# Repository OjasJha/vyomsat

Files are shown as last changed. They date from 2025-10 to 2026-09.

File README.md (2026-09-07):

> [!IMPORTANT]
> ## 🚀 VyomSat has moved
>
> Active development now lives under the **[VyomSat](https://github.com/vyomsat)** GitHub organization. This personal repository is no longer the source of truth for the classroom satellite, ground software, or educational research.

| 🧩 **This repository** | 🛰️ **VyomSat Alpha** |
|:---|:---|
| Archived **FlatSat** | Current **1U** classroom CubeSat |
| 🔌 Breadboard wiring, buses, and subsystem bring-up | 🧱 Custom **PCB**, enclosure, and functioning assembly |
| 🧪 Bench testing and historical reference | 🛠️ Hardware, firmware, and mission-cycle testing |
| 📦 Not the source of truth | ⚠️ Educational bench platform (**not flight-qualified**) |

### 🔗 Continue under the VyomSat organization

| | Project | What you will find |
|:---:|:---|:---|
| 🛰️ | **[VyomSat Alpha](https://github.com/vyomsat/vyomsat-alpha)** | PCB-based **1U** classroom CubeSat: hardware, firmware, enclosure, subsystem validation, and mission-cycle testing |
| 📡 | **[Ground Station](https://github.com/vyomsat/vyomsat-alpha-ground-station)** | Browser mission console: USB telemetry, spacecraft commands, parsed health data, and live GPS visualization |
| 🎓 | **[Impact Study](https://github.com/vyomsat/vyomsat-alpha-impact-study)** | Educational-efficacy research: study design, field data, and analysis |

> [!WARNING]
> ⚠️ **Not flight-qualified.** VyomSat Alpha is a functioning educational CubeSat for the classroom bench. It is not spacecraft hardware intended for orbital deployment.

> [!NOTE]
> 📦 This repository is **archived** and retained for historical reference. Please star, fork, open issues, and contribute on the organization repositories above.

---

# VyomSat - Essence of Space. Built by You.

**A step-by-step learning kit for exploring microsatellite technology through hands-on CubeSat development**

🛰️ **Learn by Building** | 📚 **Model-Based Learning** | 🔧 **Off-the-Shelf Components** | 🚀 **Space Technology Made Accessible**

---

## 📖 Overview

VyomSat is an educational kit designed to make space technology accessible through hands-on learning. This repository guides you through building a functional CubeSat prototype from the ground up, one subsystem at a time, using readily available components and a Raspberry Pi Pico microcontroller.

### The Name

**Vyom** (व्योम) means sky, heavens, or outer space in Sanskrit.  
**Sat** ties to "satellite," but in Sanskrit also means truth, being, existence.

VyomSat can be read as:
- **"Space Satellite"** - straightforward and modern
- **"Truth of Space" / "Essence of the Sky"** - deeper, Sanskrit-inspired meaning

Short, internationally pronounceable, with both technical and cultural essence. 🚀✨

---

## 🎯 Mission & Vision

### Why This Project Exists

This project was born from a gap in STEM education: high school students often lack opportunities for truly challenging, real-world engineering experiences beyond rudimentary activities like water rockets or spaghetti towers. VyomSat aims to fill this gap by providing a comprehensive, hands-on introduction to space systems engineering.

### Mission
**Make space technology accessible to learners of all ages and expertise levels.**

### Vision
**Share knowledge about microsatellite technology through a practical kit that offers hands-on training and meaningful interaction with real engineering systems.**

Space is the final frontier, and it's also one of the best ways to learn engineering in a multidisciplinary way.

---

## 👥 Who Is This For?

**Target Audience:**
- 🔬 STEM enthusiasts
- 🛠️ Tinkerers and makers
- 🎨 DIY electronics hobbyists
- 🌌 Anyone interested in space, CubeSats, and satellites
- 📚 **Age no bar!** Anyone with high school-level science and basic programming can jump in

**Prerequisites:**
- Basic breadboarding skills
- Familiarity with Raspberry Pi Pico
- Basic MicroPython programming (or willingness to learn)
- A lot of curiosity! 🧠✨

---

## 🚀 Why CubeSats? Why Model-Based Learning?

### CubeSats as Learning Platforms

CubeSats (miniature satellites using standardized 10×10×10 cm units) are excellent platforms for learning because they:
- Cover **multidisciplinary engineering**: electrical, mechanical, software, communications
- Demonstrate **real-world constraints**: power, mass, volume, thermal management
- Introduce **systems engineering**: subsystems must work together seamlessly
- Are **achievable**: built with off-the-shelf components at educational scales
- Reflect **modern space technology**: actual CubeSats fly in orbit regularly

### Model-Based, Step-by-Step Learning

This repository uses a **progressive building approach**:
1. Start with foundational subsystems (power, communication)
2. Add sensors and payloads incrementally
3. Integrate everything into a working prototype
4. Understand the **what, why, and how** of each component

Each step builds on the previous one, allowing you to:
- ✅ Master one concept before moving to the next
- ✅ Troubleshoot issues in isolated subsystems
- ✅ Understand system integration challenges
- ✅ Build confidence through working prototypes

---

## 📂 Repository Structure

This repository contains **6 progressive steps**, each adding new capabilities to your CubeSat:

### **Step 0: EPS + COM Integration** (`step-00-eps-com/`)
**Electrical Power System (EPS) and Communication (COM)**
- Battery voltage monitoring via ADC
- OLED display for local visualization
- XBee UART communication for wireless telemetry
- Foundation for all subsequent steps

**Key Components:** Raspberry Pi Pico, OLED display (SSD1306), XBee module  
**Learn:** Power monitoring, I2C, UART, telemetry basics

---

### **Step 1: 9-Axis IMU Integration** (`step-01-9axis/`)
**Attitude Determination and Control System (ADCS) - Sensing**
- MPU9250 9-axis IMU (accelerometer + gyroscope + magnetometer)
- Pitch, roll, and heading calculations
- Sensor fusion for accurate attitude estimation
- Command-triggered comprehensive attitude data capture

**New Components:** MPU9250 9-axis IMU  
**Learn:** Inertial measurement, sensor fusion, attitude determination

---

### **Step 2: GPS Integration** (`step-02-gps/`)
**Navigation and Positioning**
- NEO-6M GPS module for precise location tracking
- Latitude, longitude, altitude, and satellite data
- GPS time synchronization with timezone support
- Speed and course over ground measurement

**New Components:** NEO-6M GPS module  
**Learn:** NMEA sentence parsing, GPS fundamentals, position tracking

---

### **Step 3: Camera Integration** (`step-03-camera/`)
**Payload - Earth Observation**
- ArduCam Mega 3MP camera for high-resolution imaging
- JPEG image capture with configurable quality
- Auto-incremented filenames for organized storage
- Command-triggered photo capture

**New Components:** ArduCam Mega 3MP (OV5642)  
**Learn:** SPI camera interfacing, image capture, payload operations

---

### **Step 4: SD Card Integration** (`step-04-sd/`)
**Data Storage and Mission Data Logging**
- Micro SD card module for comprehensive data logging
- Multi-sensor data capture (housekeeping, 9-axis, GPS)
- Multi-cycle data collection with timestamped log files
- FAT32 filesystem support for easy data retrieval

**New Components:** Micro SD Card module, Micro SD card (up to 32GB)  
**Learn:** Filesystem operations, data logging, long-term storage

---

### **Step 5: Photo-to-SD Automatic Transfer** (`step-05-photo-move.py/`)
**Intelligent File Management**
- Automatic image transfer to SD card after capture
- Flash memory freed immediately after each photo
- Preserved auto-incremented filenames
- Centralized storage for all mission data

**New Features:** Enhanced camera workflow, automated file management  
**Learn:** Storage optimization, mission operations, file I/O

---

## 🛠️ What's Provided for Each Step

Every step directory includes:

- ✅ **Complete README.md** - Detailed documentation with theory and operation
- ✅ **Circuit Schematic** - Full electrical connections (`*_schematic.png`)
- ✅ **Breadboard Layout** - Physical wiring guide (`*_breadboard.png`)
- ✅ **Bill of Materials** - Complete parts list with specifications (`*_bom.html`)
- ✅ **Fritzing File** - Editable circuit diagram (`*.fzz`)
- ✅ **MicroPython Code** - Modular manager scripts for each subsystem

### Fritzing Software

Circuit diagrams were created using [**Fritzing**](https://fritzing.org/), an open-source electronics design tool.

📥 **Download Fritzing:** [fritzing.org/download](https://fritzing.org/download/)

You can view, edit, or customize the `.fzz` files to adapt the designs to your needs.

---

## 📚 Required Libraries

All sensor and breakout board libraries are maintained in a separate repository for modularity and reusability.

🔗 **MicroPython Libraries:** [github.com/OjasJha/micropython-lib](https://github.com/OjasJha/micropython-lib.git)

**To get started:**
```bash
git clone https://github.com/OjasJha/micropython-lib.git
```

**Copy required libraries** (listed in each step's README) to your Raspberry Pi Pico in a flat structure alongside the VyomSat manager modules.

---

## 🚦 Quick Start Guide

### 1. **Hardware Setup**
- Gather components from the Bill of Materials (BOM) for your chosen step
- Follow the breadboard layout diagram for wiring
- Double-check connections against the schematic

### 2. **Software Setup**
- Install [Thonny IDE](https://thonny.org/) for MicroPython development
- Install MicroPython firmware on your Raspberry Pi Pico 2 or Pico W
- Download required libraries from the [micropython-lib repository](https://github.com/OjasJha/micropython-lib.git)

### 3. **Upload Code**
- Copy library files (e.g., `uart_handler.py`, `ssd1306_handler.py`) to Pico
- Copy VyomSat manager modules (e.g., `vyomsat_battery_manager.py`) to Pico
- Copy main script (`vyomsat.py`) to Pico

### 4. **Run and Test**
- Open Thonny, connect to your Pico
- Run `vyomsat.py` or rename it to `main.py` for auto-start on boot
- Monitor USB serial console (115200 baud) for debug output
- Test commands via XBee UART interface

### 5. **Build Progressively**
- Start with Step 0 to establish the foundation
- Add one subsystem at a time (Steps 1 → 2 → 3 → 4 → 5)
- Test thoroughly at each step before proceeding
- Refer to individual README files for detailed instructions

---

## 📊 Communication Interfaces Summary

By Step 5, your CubeSat prototype will use:

| Interface | Pins | Speed | Purpose |
|---|---|---|---|
| **SPI0** | GP16/17/18/19 | 8 MHz | ArduCam Mega 3MP Camera |
| **SPI1** | GP10/11/12/13 | 1 MHz | Micro SD Card Module |
| **UART0** | GP0/GP1 | 9600 bps | XBee Communication |
| **UART1** | GP4/GP5 | 9600 bps | NEO-6M GPS Module |
| **I2C0** | GP6/GP7 | 400 kHz | SSD1306 OLED Display |
| **I2C1** | GP20/GP21 | 400 kHz | MPU9250 9-Axis IMU |
| **ADC** | GP28 | - | Battery Voltage Monitoring |

---

## 🎓 Learning Outcomes

By completing this project, you will:

### Technical Skills
- ✅ Understand **CubeSat subsystems**: EPS, COM, ADCS, GPS, Camera, Data Storage
- ✅ Master **communication protocols**: I2C, SPI, UART, ADC
- ✅ Learn **sensor integration**: IMU, GPS, camera interfacing
- ✅ Practice **embedded programming**: MicroPython on Raspberry Pi Pico
- ✅ Develop **systems thinking**: integrating multiple subsystems
- ✅ Handle **real-world constraints**: power, memory, timing, bus contention

### Engineering Practices
- ✅ **Modular design**: Each subsystem isolated and testable
- ✅ **Progressive integration**: Build complexity incrementally
- ✅ **Error handling**: Graceful degradation when components fail
- ✅ **Documentation**: Reading schematics, datasheets, and technical docs
- ✅ **Troubleshooting**: Debugging hardware and software issues

### Space Technology Knowledge
- ✅ How **satellites monitor power** (battery voltage sensing)
- ✅ How **satellites determine attitude** (IMU sensors and fusion algorithms)
- ✅ How **satellites know their position** (GPS and NMEA parsing)
- ✅ How **satellites capture images** (camera payloads)
- ✅ How **satellites store data** (onboard storage and file management)
- ✅ How **satellites communicate** (telemetry and command interfaces)

### What You'll Have Built
A **working CubeSat prototype** that:
- 🔋 Monitors battery voltage
- 📡 Communicates wirelessly via XBee
- 📺 Displays telemetry on OLED screen
- 🧭 Tracks orientation and motion
- 🛰️ Determines GPS position
- 📷 Captures high-resolution images
- 💾 Logs all sensor data to SD card
- ⚡ Manages storage efficiently

---

## 🧑‍💻 Supported UART Commands

Once fully built (Step 5), your CubeSat responds to these commands via XBee:

| Command | Function | Introduced In |
|---|---|---|
| **`v`** | Battery voltage reading | Step 0 |
| **`a`** | 9-axis IMU attitude data | Step 1 |
| **`g`** | GPS position and diagnostics | Step 2 |
| **`c`** | Camera capture + SD transfer | Step 3 (enhanced in Step 5) |
| **`s`** | Multi-sensor data logging to SD | Step 4 |

---

## 🔧 Built With Off-the-Shelf Components

All components are readily available from electronics suppliers like Adafruit, SparkFun, Amazon, or local vendors:

- **Raspberry Pi Pico 2** or **Pico W** (microcontroller)
- **SSD1306 OLED Display** (128×64, I2C)
- **MPU9250 9-Axis IMU** (GY-9250 module)
- **NEO-6M GPS Module** (GY-GPS6MV2)
- **ArduCam Mega 3MP Camera** (OV5642, SPI)
- **Micro SD Card Module** (SPI)
- **XBee Module** (or compatible UART device)
- Breadboard, jumper wires, resistors, batteries

**Total cost:** Approximately $80-$150 USD depending on component sources.

---

## 📁 Project Structure

```
vyomsat/
│
├── README.md                          # This file - repository overview
├── LICENSE                            # MIT License
│
├── step-00-eps-com/                   # Step 0: Power & Communication
│   ├── README.md                      # Detailed step documentation
│   ├── vyomsat.py                     # Main integration script
│   ├── vyomsat_battery_manager.py     # Battery voltage monitoring
│   ├── vyomsat_oled_manager.py        # OLED display handler
│   ├── vyomsat_xbee_manager.py        # XBee reset handler
│   ├── eps-com_schematic.png          # Circuit schematic
│   ├── eps-com_breadboard.png         # Breadboard layout
│   ├── eps-com_bom.html               # Bill of materials
│   └── eps-com.fzz                    # Fritzing design file
│
├── step-01-9axis/                     # Step 1: 9-Axis IMU
│   ├── README.md
│   ├── vyomsat.py
│   ├── vyomsat_9axis_manager.py       # NEW: IMU handler
│   ├── [other managers]
│   ├── 9axis_schematic.png
│   ├── 9axis_breadboard.png
│   ├── 9axis_bom.html
│   └── 9axis.fzz
│
├── step-02-gps/                       # Step 2: GPS Integration
│   ├── README.md
│   ├── vyomsat.py
│   ├── vyomsat_gps_manager.py         # NEW: GPS handler
│   ├── [other managers]
│   ├── gps_schematic.png
│   ├── gps_breadboard.png
│   ├── gps_bom.html
│   └── gps.fzz
│
├── step-03-camera/                    # Step 3: Camera Integration
│   ├── README.md
│   ├── vyomsat.py
│   ├── vyomsat_camera_manager.py      # NEW: Camera handler
│   ├── [other managers]
│   ├── camera_schematic.png
│   ├── camera_breadboard.png
│   ├── camera_bom.html
│   └── camera.fzz
│
├── step-04-sd/                        # Step 4: SD Card Logging
│   ├── README.md
│   ├── vyomsat.py
│   ├── vyomsat_sd_manager.py          # NEW: SD card handler
│   ├── [other managers]
│   ├── sd_schematic.png
│   ├── sd_breadboard.png
│   ├── sd_bom.html
│   └── sd.fzz
│
└── step-05-photo-move.py/             # Step 5: Auto Photo-to-SD
    ├── README.md
    ├── vyomsat.py                     # Enhanced with auto-transfer
    ├── vyomsat_sd_manager.py          # Enhanced with move function
    ├── [other managers]
    ├── photo-move_schematic.png
    ├── photo-move_breadboard.png
    ├── photo-move_bom.html
    └── photo-move.fzz
```

---

## 🤝 Contributing

This is an educational project developed to share knowledge about space technology. Contributions, suggestions, and improvements are welcome!

**Ways to contribute:**
- Report issues or bugs
- Suggest new features or subsystems
- Improve documentation
- Share your build photos and experiences
- Adapt designs for different hardware platforms

---

## 📜 License

**MIT License** - Copyright (c) 2025 Ojas Jha

See [LICENSE](LICENSE) file for full license text.

This project is open-source and free to use for educational purposes. You may use, modify, and distribute this project with attribution.

---

## 👨‍🚀 Author

**Ojas Jha**  
VyomSat CubeSat Education Kit  
Date: October 25, 2025

Passionate about making space technology accessible to learners worldwide. 🌍🚀

---

## 🙏 Acknowledgments

- The maker and open-source hardware communities for inspiration
- [Fritzing](https://fritzing.org/) for circuit design software
- [MicroPython](https://micropython.org/) for embedded Python support
- The CubeSat community for demonstrating that space is accessible
- High school STEM educators pushing for deeper learning experiences

---

## 🌟 Get Started Today!

Ready to build your own CubeSat prototype?

1. ⭐ **Star this repository** to bookmark it
2. 📥 **Clone or download** the repository
3. 🛒 **Order components** from the Step 0 BOM
4. 📖 **Read** `step-00-eps-com/README.md`
5. 🔧 **Start building!**

**Questions?** Open an issue or discussion. **Built something cool?** Share your results!

---

**VyomSat - Because space is for everyone. 🌌✨**

*"The essence of space, built by you."*

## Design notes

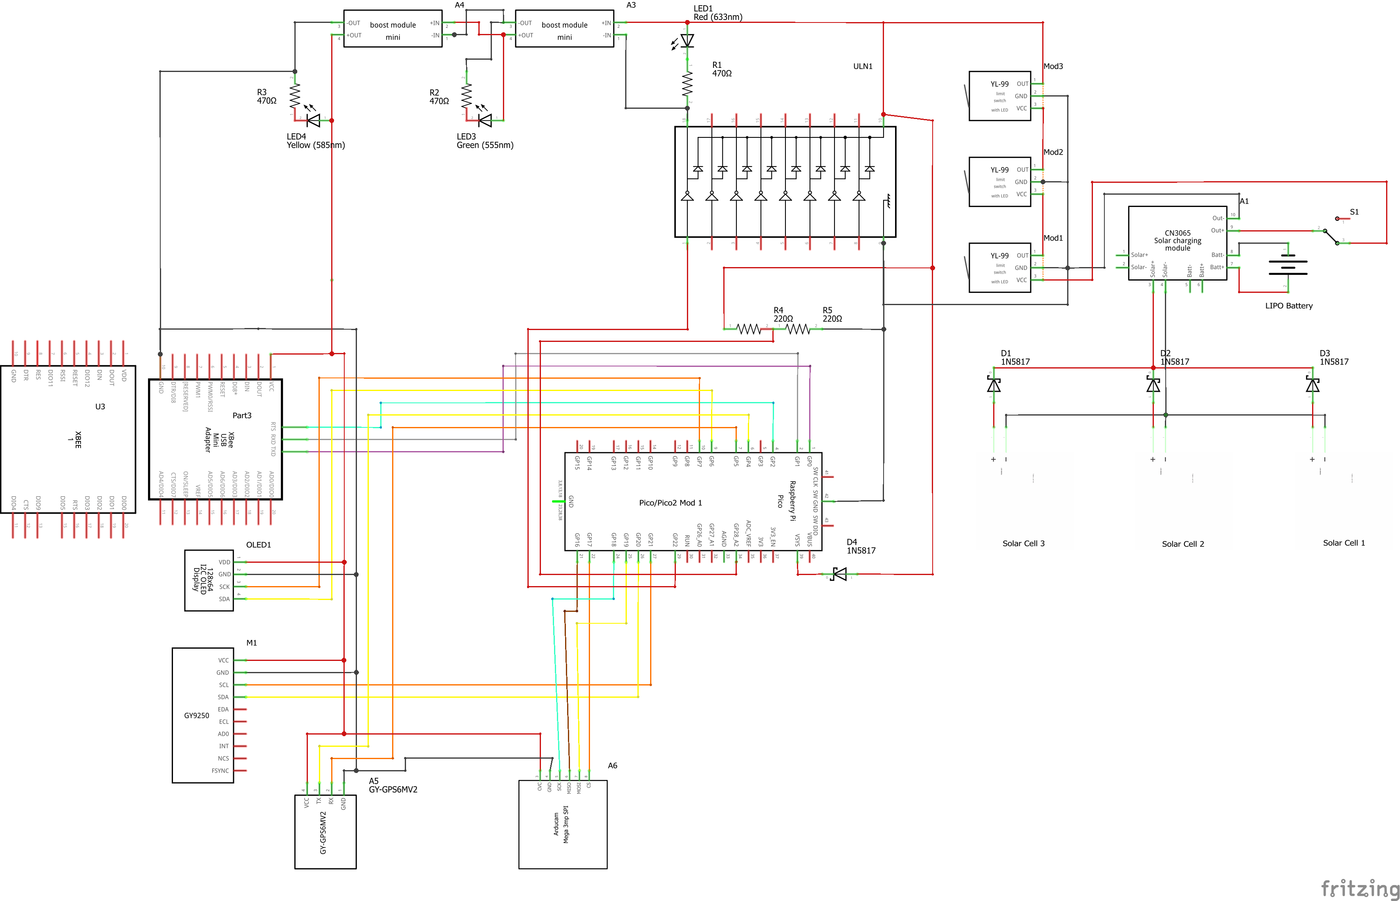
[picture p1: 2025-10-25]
step-03-camera/camera_schematic.png

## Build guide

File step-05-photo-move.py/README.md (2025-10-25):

# VyomSat Step 5: Photo Capture with Automatic SD Card Storage

**VyomSat - Essence of Space. Built by You.**

This step builds upon Step 4 (EPS + COM + 9-Axis IMU + GPS + Camera + SD Card) by adding **automatic image transfer to SD card**. When a photo is captured, the system now automatically moves it from the Pico's internal flash memory to the SD card, preserving precious onboard storage space for mission-critical operations.

## Overview

Step 5 enhances the camera imaging system with intelligent file management. The system continuously measures battery voltage, communicates via UART, provides comprehensive attitude data through the MPU9250 IMU, tracks precise geographic location using GPS satellites, captures high-quality images on command, logs sensor data to SD card, and **now automatically transfers captured images to SD card storage**.

**New in Step 5:**
- 📸 **Automatic Photo-to-SD Transfer** - Images automatically moved to SD card after capture
- 🗑️ **Flash Memory Management** - Original files deleted after successful SD transfer
- 🔄 **Seamless Integration** - Single command 'c' handles capture AND storage
- 💾 **Preserved Filenames** - Original auto-incremented names maintained on SD card
- 📺 **Enhanced Feedback** - OLED shows both capture and transfer status
- ⚡ **Optimized Storage** - Pico flash freed immediately after each photo

**Retained from Step 4:**
- 💾 Micro SD Card Module with multi-sensor data logging
- 📝 Multi-cycle sensor data capture (housekeeping, 9-axis IMU, GPS)
- 🎯 Command 's' for comprehensive sensor data logging
- 📊 Timestamped log files

**Retained from Step 3:**
- 📷 ArduCam Mega 3MP Camera with JPEG capture
- 🖼️ Auto-incremented image filenames
- 🎯 Command 'c' for camera capture (now with SD storage)

**Retained from Step 2:**
- 🛰️ NEO-6M GPS Module with position tracking
- 📍 Location Data (latitude, longitude, altitude)
- 🕐 GPS Time & Date with timezone conversion
- 🎯 Command 'g' for GPS data capture

**Retained from Step 1:**
- 🧭 MPU9250 9-Axis IMU (accelerometer, gyroscope, magnetometer)
- 📊 Attitude Data (pitch, roll, heading)
- 🎯 Command 'a' for 9-axis data capture

**Retained from Step 0:**
- 📊 Battery Voltage Monitoring
- 📺 OLED Display (128x64 SSD1306)
- 📡 UART Communication (XBee)
- 🎛️ Command Interface
- ⚡ Hardware Reset Management

## Features

### Photo-to-SD Automatic Transfer (NEW)

The enhanced camera capture system now includes intelligent file management:

- **Automatic Transfer**: Images automatically moved to SD card after capture
- **Original Filename Preserved**: Auto-incremented names maintained (e.g., `vyomsat_image_003.jpg`)
- **Flash Memory Freed**: Original file deleted from Pico after successful transfer
- **Error Handling**: Graceful degradation if SD card unavailable
- **User Feedback**: OLED displays both capture and transfer status
- **UART Responses**: ACK/NAK for both operations

**Photo Capture & Transfer Process:**
1. Command 'c' received via UART
2. OLED shows "Camera" / "Capturing..."
3. Camera captures JPEG image to Pico flash
4. Image saved with auto-incremented filename
5. OLED shows success with filename (3 seconds)
6. OLED shows "Moving to" / "SD card..."
7. File copied to SD card at `/sd/[filename]`
8. Original file deleted from Pico flash
9. OLED shows "Moved to SD!" with filename (2 seconds)
10. UART sends final ACK: "Image saved to SD card"
11. System returns to normal telemetry display

**Benefits:**
- **Storage Efficiency**: Pico flash memory freed immediately
- **Centralized Storage**: All mission data (images + logs) on SD card
- **Mission Longevity**: More photos possible without flash exhaustion
- **Easy Retrieval**: Single SD card contains all mission data
- **Automated Workflow**: No manual file management required

### SD Card Data Logging Capabilities (from Step 4)

The Micro SD Card module provides comprehensive data storage:

- **Multi-Sensor Data Logging**: Comprehensive telemetry capture
  - Housekeeping Data: Battery voltage, timestamps, system uptime
  - 9-Axis IMU Data: Accelerometer, gyroscope, magnetometer, attitude, heading
  - GPS Data: Position, altitude, time, satellites, motion, fix quality
  - Multi-cycle collection: 5 cycles by default (configurable)
  - Cycle timing: 500ms delay between cycles (configurable)

- **Image Storage**: High-resolution JPEG images
  - Auto-incremented filenames: vyomsat_image_XXX.jpg
  - Preserved from original capture
  - Stored at SD card root: /sd/
  - 3MP resolution (2048x1536 pixels)

- **File Management**: Automatic operations
  - Sensor logs: sensor_log_[timestamp].txt
  - Camera images: vyomsat_image_XXX.jpg
  - Unix timestamp for logs
  - Auto-increment counter for images
  - No file overwrites

- **SPI Communication**: High-speed SD card access
  - SPI Bus 1: 1 MHz communication speed (safe initialization)
  - 4-wire interface: SCK, MISO, MOSI, CS
  - Dedicated chip select for SD card control
  - FAT filesystem mounting

- **Card Compatibility**: Wide range of SD cards
  - SDSC (Standard Capacity): Up to 2GB, FAT16
  - SDHC (High Capacity): 2GB to 32GB, FAT32
  - Recommended: FAT32 formatted cards

## Hardware Requirements

### Components

- Raspberry Pi Pico 2 or Pico W
- SSD1306 OLED Display (128x64 pixels, I2C)
- MPU9250 9-Axis IMU Sensor Module (I2C)
- NEO-6M GPS Module (UART)
- ArduCam Mega 3MP SPI Camera Module (OV5642)
- Micro SD Card Module (SPI)
- **Micro SD Card (FAT32, up to 32GB, sufficient space for images)** ← **IMPORTANT**
- XBee module (or compatible UART device)
- Battery voltage divider circuit
- 4.7kΩ pull-up resistors for I2C lines (2x for IMU)

### Wiring Connections

| Component | Pico Pin | Description |
|---|---|---|
| **OLED Display** | | |
| SCL | GP7 | I2C Serial Clock |
| SDA | GP6 | I2C Serial Data |
| VCC | 3.3V | Power |
| GND | GND | Ground |
| **MPU9250 9-Axis IMU** | | |
| SCL | GP21 | I2C Serial Clock |
| SDA | GP20 | I2C Serial Data |
| VCC | 3.3V | Power |
| GND | GND | Ground |
| **NEO-6M GPS Module** | | |
| TX (GPS → Pico) | GP5 | UART1 Receive |
| RX (Pico → GPS) | GP4 | UART1 Transmit |
| VCC | 3.3V | Power |
| GND | GND | Ground |
| **ArduCam Mega 3MP** | | |
| SCK | GP18 | SPI0 Serial Clock |
| MISO | GP16 | SPI0 Master In Slave Out |
| MOSI | GP19 | SPI0 Master Out Slave In |
| CS | GP17 | SPI0 Chip Select |
| VCC | 3.3V or 5V | Power (check module specs) |
| GND | GND | Ground |
| **Micro SD Card Module** | | |
| SCK | GP10 | SPI1 Serial Clock |
| MISO | GP12 | SPI1 Master In Slave Out |
| MOSI | GP11 | SPI1 Master Out Slave In |
| CS | GP13 | SPI1 Chip Select |
| VCC | 3.3V or 5V | Power (module has regulator) |
| GND | GND | Ground |
| **XBee Module** | | |
| TX (Pico → XBee) | GP0 | UART0 Transmit |
| RX (XBee → Pico) | GP1 | UART0 Receive |
| RST | GP2 | Hardware Reset (optional) |
| GND | GND | Common Ground |
| **Battery Sensing** | | |
| ADC Input | GP28 | Battery voltage via divider |

> **Important Notes**: 
> - The SD Card Module uses SPI1 communication at 1 MHz (safe initialization speed)
> - **SD card should be formatted as FAT32 with sufficient free space for images**
> - Each 3MP JPEG image is typically 200KB-800KB depending on scene complexity
> - SPI Bus 0 (GP16/GP17/GP18/GP19) is dedicated to camera
> - SPI Bus 1 (GP10/GP11/GP12/GP13) is dedicated to SD card
> - UART1 (GP4/GP5) remains for GPS communication
> - UART0 (GP0/GP1) remains for XBee communication
> - The MPU9250 requires 4.7kΩ pull-up resistors on both SCL and SDA lines
> - Battery voltage must be reduced to 0-3.3V range using a voltage divider circuit
> - SD card module typically includes level shifters for 5V compatibility

### Circuit Diagrams

Visual references for hardware setup are provided using Fritzing diagrams:

#### Schematic Diagram
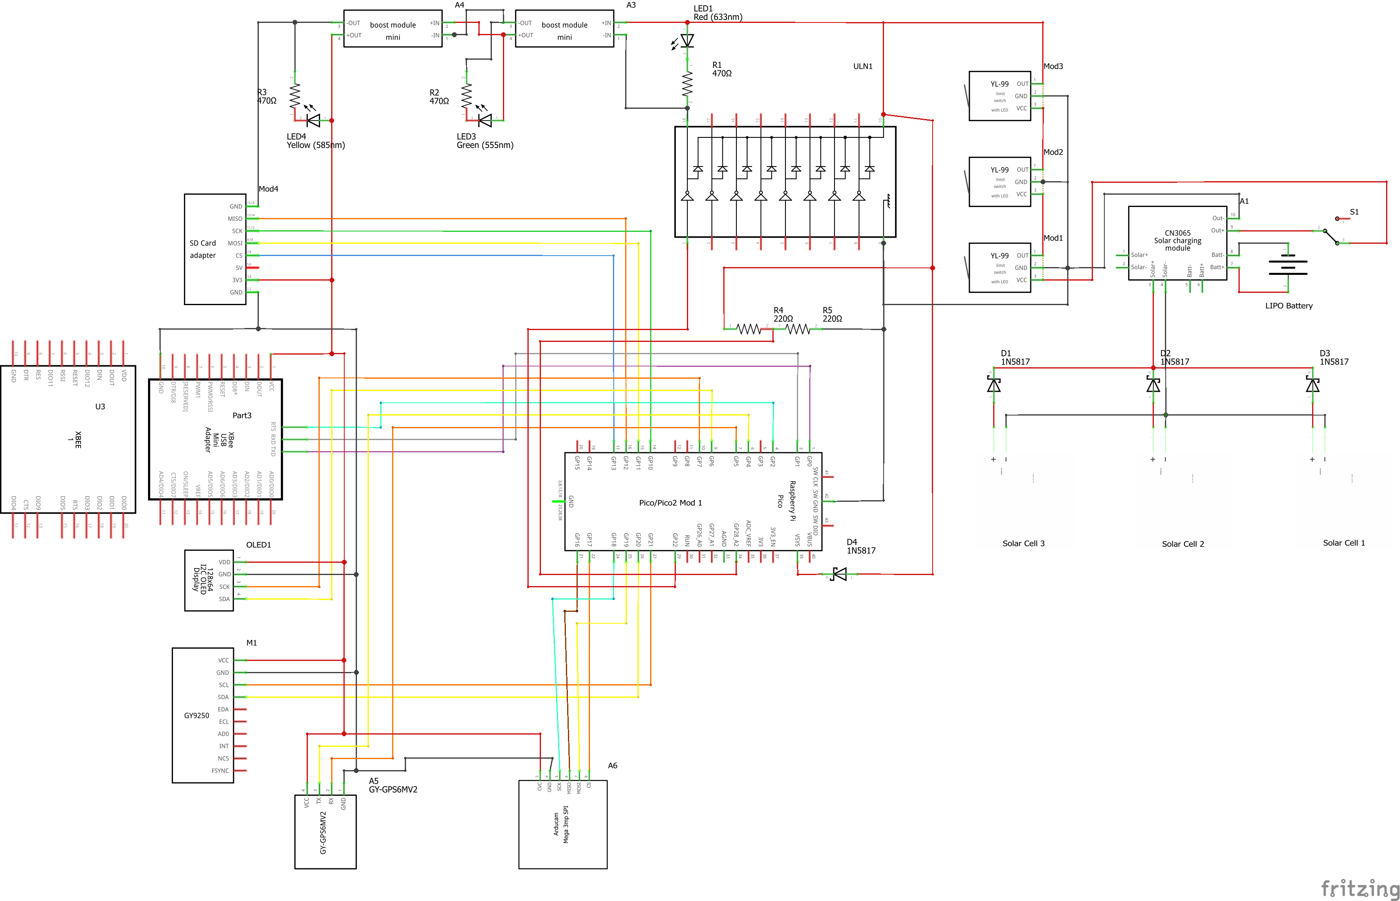
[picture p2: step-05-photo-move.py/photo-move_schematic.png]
VyomSat Photo-to-SD Schematic


The schematic shows the complete electrical connections including:
- Solar panel array with charge controller (CN3065)
- Multiple power rails (3.3V, 5V) with boost/buck converters
- Raspberry Pi Pico/Pico2 connections
- OLED display I2C interface (GP6/GP7)
- MPU9250 9-axis IMU I2C interface (GP20/GP21)
- NEO-6M GPS module UART1 interface (GP4/GP5)
- ArduCam Mega 3MP SPI0 interface (GP16/GP17/GP18/GP19)
- Micro SD Card Module SPI1 interface (GP10/GP11/GP12/GP13)
- XBee communication module on UART0 (GP0/GP1)
- Battery voltage sensing circuit
- LED status indicators
- Limit switches for mission control
- Power management components

#### Breadboard Layout
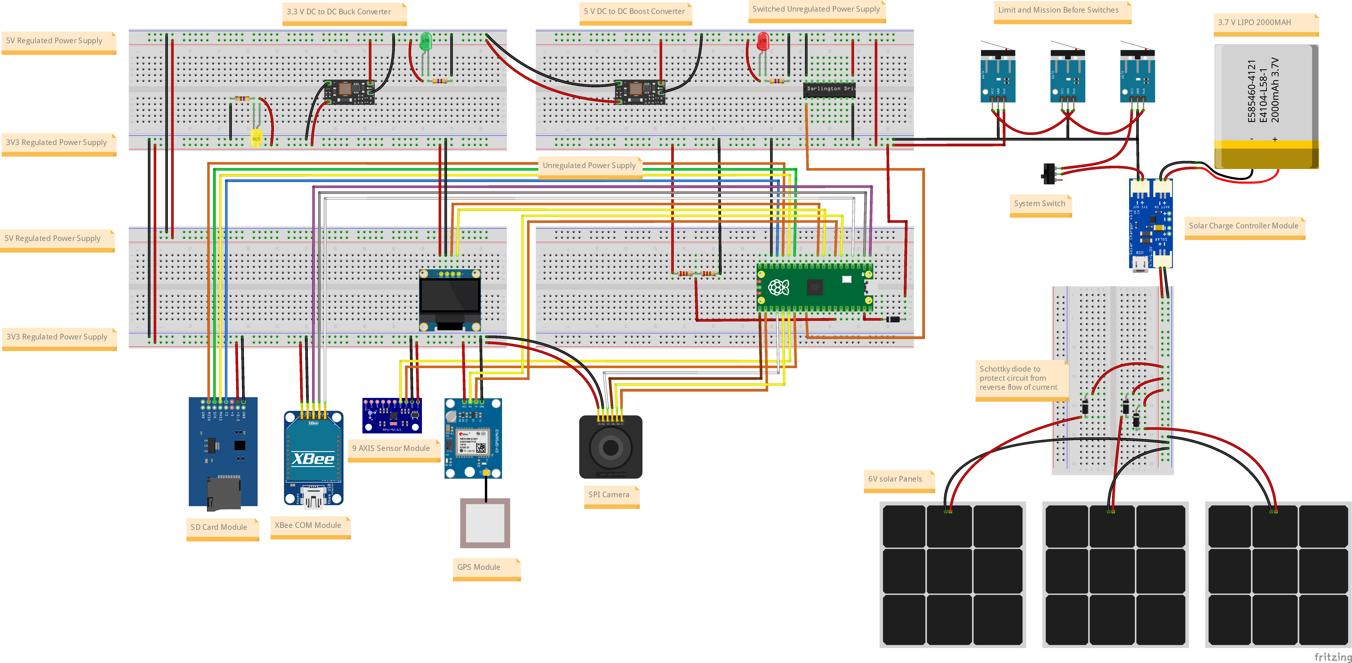
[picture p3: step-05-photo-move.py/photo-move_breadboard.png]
VyomSat Photo-to-SD Breadboard


The breadboard layout provides a practical wiring guide showing:
- Physical component placement
- Wire routing and connections
- Power distribution
- Module interconnections
- Camera module positioning and SPI0 connections
- SD card module positioning and SPI1 connections
- GPS module with antenna

#### Bill of Materials (BOM)
A complete parts list with quantities and specifications is available: **[photo-move_bom.html](photo-move_bom.html)**

The BOM includes all components from Steps 0, 1, 2, 3, and 4:
- Micro SD Card Module with SPI interface
- ArduCam Mega 3MP Camera Module
- Level conversion support (5V or 3.3V)
- 42mm × 24mm × 12mm form factor
- Supports Micro SD (≤2GB) and Micro SDHC (≤32GB) cards
- All resistors, capacitors, ICs, and modules required

> **Fritzing Software**: These diagrams were created using [Fritzing](https://fritzing.org/), an open-source electronics design tool. Download from [fritzing.org/download](https://fritzing.org/download/) to view or modify the designs.

## Architecture

The system builds on Step 4's modular architecture with enhanced camera-to-SD integration:

### Updated Module: `vyomsat.py`
Main integration module with enhanced command 'c' handler.

**Changes from Step 4:**
- Updated command 'c' handler to automatically move images to SD card
- Added call to `move_file_to_sd()` after successful image capture
- Enhanced error handling for photo-to-SD transfer
- Improved UART response messages for complete workflow
- Documentation updated for automatic photo transfer

**Command 'c' Handler Flow:**
```
Command 'c' received
    ↓
Display "Capturing..." on OLED
    ↓
Call capture_and_display_image()
    - Captures photo to Pico flash
    - Returns filename if successful
    ↓
If capture successful:
    Display success on OLED (3 seconds)
    ↓
    Display "Moving to SD..." on OLED
    ↓
    Call move_file_to_sd()
        - Copy file to SD card
        - Delete original from flash
        - Display success on OLED
        - Send UART ACK
    ↓
Resume normal telemetry
```

### Enhanced Module: `vyomsat_sd_manager.py`
SD card manager with new file transfer functionality.

**New Function:**
- `move_file_to_sd()`: Moves captured images from Pico flash to SD card

**Key Features:**
- Copies file content from source to SD card destination
- Preserves original filename (auto-incremented camera names)
- Deletes original file after successful copy
- Provides OLED feedback during transfer
- Sends ACK/NAK responses via UART
- Error handling for SD card unavailability
- Warning if file deletion fails (still counts as success since copy worked)

**File Transfer Process:**
1. Check if SD card is initialized
2. Extract filename from source path
3. Build destination path: `/sd/[filename]`
4. Display "Moving to SD..." on OLED
5. Open source file in binary read mode
6. Read entire file content into memory
7. Open destination file in binary write mode
8. Write content to SD card
9. Delete original file from Pico flash
10. Display "Moved to SD!" on OLED (2 seconds)
11. Send UART ACK: "Image saved to SD card"

**OLED Display Feedback:**
During photo-to-SD transfer:
1. **Transfer Screen**: "Moving to" / "SD card..." (during copy)
2. **Success Screen**: "Moved to SD!" / filename (2 seconds)
3. **Error Screen**: "SD Move Error!" / "Failed" (2 seconds)

### Retained Modules from Previous Steps

**`vyomsat_camera_manager.py`**: ArduCam Mega camera management (Step 3)  
**`vyomsat_gps_manager.py`**: NEO-6M GPS sensor management (Step 2)  
**`vyomsat_9axis_manager.py`**: MPU9250 9-axis IMU sensor management (Step 1)  
**`vyomsat_battery_manager.py`**: Battery voltage sensing via ADC (Step 0)  
**`vyomsat_oled_manager.py`**: SSD1306 OLED display management (Step 0)  
**`vyomsat_xbee_manager.py`**: XBee hardware reset handling (Step 0)

## Telemetry Output

### USB Serial Console - Normal Operation
```
[12345ms] Telemetry Sent | V: 6.90V | GPS: 25.2521, 55.3095 | Alt: 15.2m | Sats: 8 | Counter: 42
```

### USB Serial Console - Photo Capture with SD Transfer (Command 'c')
```
UART Command Received: 'c' (ASCII: 99)
Processing camera image capture...
USB Response: Command 'c' received: Camera capture initiated
[INFO] Starting camera capture...
[INFO] Image captured, processing...
[INFO] Saving image as 'vyomsat_image_003.jpg'...
[OK] Image saved as vyomsat_image_003.jpg
[OK] Camera capture SUCCESS: Image saved as vyomsat_image_003.jpg
SD Manager: Moving file to SD card...
  Source: vyomsat_image_003.jpg
  Destination: /sd/vyomsat_image_003.jpg
[OK] SD Manager: File copied to SD card
[OK] SD Manager: Original file deleted
[OK] SD Manager: File moved to SD card: vyomsat_image_003.jpg
UART Response sent: 'ACK: Image saved to SD card' (30 bytes)
```

### USB Serial Console - Photo Capture with SD Error
```
UART Command Received: 'c' (ASCII: 99)
Processing camera image capture...
[OK] Camera capture SUCCESS: Image saved as vyomsat_image_004.jpg
[ERROR] SD Manager: File move failed: SD card not initialized
UART Response sent: 'NAK: SD card not available' (28 bytes)
```

### UART (XBee) - Photo Capture Success
```
ACK: Camera capture initiated
ACK: Image saved as vyomsat_image_003.jpg
ACK: Image saved to SD card
```

### UART (XBee) - SD Transfer Failure
```
ACK: Camera capture initiated
ACK: Image saved as vyomsat_image_004.jpg
NAK: SD card not available
```

### OLED Display - Photo Capture with SD Transfer (Success)
```
[Screen 1 - 0s]
Camera
Capturing...

[Screen 2 - 2s]
Camera OK!
Image saved:
vyomsat_image_00
3.jpg

[Screen 3 - 5s]
Moving to
SD card...

[Screen 4 - 7s]
Moved to SD!
vyomsat_image_00
3.jpg

[Screen 5 - 9s]
VyomSat EPS+GPS
00:05:42
V: 6.90V
Lat:25.2521° N
```

### OLED Display - Normal Operation
```
VyomSat EPS+GPS
00:05:42
V: 6.90V
Lat:25.2521° N
Lon:55.3095° E
```

## Supported UART Commands

Send single character commands to control the system:

| Command | Function | Response | Status |
|---|---|---|---|
| `c` | **Camera capture + SD transfer** | Image saved to SD card | **ENHANCED** ✨ |
| `s` | SD card data logging | Comprehensive sensor log saved | Active |
| `g` | GPS position data | Comprehensive GPS diagnostics | Active |
| `a` | 9-axis IMU attitude data | Comprehensive sensor data | Active |
| `v` | Request voltage reading | Detailed voltage data | Active |
| `b` | System reset | ACK (placeholder) | Reserved |

### Command 'c' - Camera Capture with SD Transfer (ENHANCED)

**Behavior:**
1. Checks if camera is initialized and available
2. Displays "Capturing..." on OLED
3. Captures JPEG image from camera (3MP resolution)
4. Saves to Pico flash with auto-incremented filename
5. Displays success on OLED with filename (3 seconds)
6. **NEW: Checks if SD card is available**
7. **NEW: Displays "Moving to SD card..." on OLED**
8. **NEW: Copies image file to SD card**
9. **NEW: Deletes original file from Pico flash**
10. **NEW: Displays "Moved to SD!" on OLED (2 seconds)**
11. Sends final ACK/NAK via UART
12. Returns to normal telemetry display

**Example:**
```
Send: c

Receive (UART): ACK: Camera capture initiated
                ACK: Image saved as vyomsat_image_003.jpg
                ACK: Image saved to SD card

Display (OLED): [Capture sequence] → [Transfer sequence] → [Normal telemetry]

Storage: vyomsat_image_003.jpg saved to SD card (/sd/)
         Original file deleted from Pico flash
```

**Photo Capture & Transfer Process:**
1. Command 'c' received via UART
2. Camera availability checked
3. OLED shows "Capturing..."
4. Camera captures 3MP JPEG image
5. Image saved to flash: vyomsat_image_XXX.jpg
6. OLED shows "Camera OK!" + filename (3 seconds)
7. **SD card availability checked**
8. **OLED shows "Moving to SD card..."**
9. **File copied to /sd/vyomsat_image_XXX.jpg**
10. **Original file deleted from flash**
11. **OLED shows "Moved to SD!" + filename (2 seconds)**
12. UART sends final ACK
13. 1-second pause before returning to telemetry

**Benefits of Automatic Transfer:**
- **Flash Memory Preserved**: Pico flash freed after each photo
- **Mission Longevity**: More photos possible without flash exhaustion
- **Centralized Storage**: All data on single SD card
- **No Manual Intervention**: Fully automated workflow
- **Error Recovery**: Graceful degradation if SD unavailable

### Command 's' - SD Card Data Logging

**Example:**
```
Send: s

Receive (UART): ACK: SD card logging initiated
                ACK: Data logged: 5 cycles saved to sensor_log_1729857309.txt

Storage: sensor_log_1729857309.txt saved to SD card
```

### Command 'g' - GPS Position Data

**Example:**
```
Send: g

Receive: ACK: GPS capture initiated
         [comprehensive GPS data follows]
```

### Command 'a' - 9-Axis Attitude Data

**Example:**
```
Send: a

Receive: ACK: MPU9250 capture initiated
         [comprehensive 9-axis IMU data follows]
```

### Command 'v' - Voltage Reading

**Example:**
```
Send: v

Receive: ACK: Battery voltage reading initiated
         [timestamp] BATTERY VOLTAGE | Batt: 6.900V | ADC: 3.450V | Raw: 32768
```

## Usage

### 1. Setup Hardware
Connect all components according to the wiring table above. Pay special attention to:
- Micro SD Card Module on SPI Bus 1 (GP10/11/12/13)
- **SD card formatted as FAT32 with sufficient free space for images**
- ArduCam Mega 3MP on SPI Bus 0 (GP16/17/18/19)
- NEO-6M GPS module on UART1 (GP4 TX, GP5 RX)
- 4.7kΩ pull-up resistors on MPU9250 I2C lines (SCL and SDA)
- Separate I2C buses for OLED (GP6/7) and IMU (GP20/21)
- Common ground connections for all modules

### 2. Prepare SD Card
- Format SD card as FAT32 (recommended for cards >2GB)
- FAT16 works for cards ≤2GB
- **Ensure sufficient free space for images** (each 3MP JPEG: 200KB-800KB)
- Estimate storage: 32GB card can hold thousands of images
- Ensure card is properly inserted in module before powering on

### 3. Get Required Libraries

The manager modules depend on sensor and breakout board libraries from the [OjasJha/micropython-lib](https://github.com/OjasJha/micropython-lib.git) repository.

Clone or download the repository:
```bash
git clone https://github.com/OjasJha/micropython-lib.git
```

**Required libraries for Step 5:**

*From Step 0:*
- `com/uart/uart_handler.py` - UART communication handler

*From Step 1:*
- `io/oled-ssd1306/ssd1306_handler.py` - SSD1306 OLED display driver
- `sensors/mpu9250/mpu9250_handler.py` - MPU9250 9-axis IMU handler
- `sensors/mpu9250/mpu6500_handler.py` - MPU6500 6-axis IMU handler
- `sensors/mpu9250/ak8963_handler.py` - AK8963 3-axis magnetometer handler
- `sensors/mpu9250/mpu9250.py` - Low-level MPU9250 driver
- `sensors/mpu9250/mpu6500.py` - Low-level MPU6500 driver
- `sensors/mpu9250/ak8963.py` - Low-level AK8963 driver

*From Step 2:*
- `sensors/gps/neo6mv2_handler.py` - NEO-6M GPS handler with NMEA parsing

*From Step 3:*
- `io/camera/camera_handler.py` - ArduCam Mega camera handler with JPEG capture

*From Step 4:*
- `io/sd-card/sdcard_handler.py` - SD card driver for SPI-based SD/SDHC cards

> **Important**: Copy these library files directly to the same folder as the VyomSat modules (flat structure). Do NOT maintain the directory structure from the repository.

### 4. Upload Code

Copy all Python files to your Raspberry Pi Pico in the **same folder**:

**VyomSat Step 5 Modules:**
- `vyomsat.py` (updated with auto photo-to-SD)
- `vyomsat_battery_manager.py`
- `vyomsat_oled_manager.py`
- `vyomsat_xbee_manager.py`
- `vyomsat_9axis_manager.py`
- `vyomsat_gps_manager.py`
- `vyomsat_camera_manager.py`
- `vyomsat_sd_manager.py` (updated with move_file_to_sd)

**Libraries from micropython-lib repository:**
- `uart_handler.py` (from `com/uart/`)
- `ssd1306_handler.py` (from `io/oled-ssd1306/`)
- `mpu9250_handler.py` (from `sensors/mpu9250/`)
- `mpu6500_handler.py` (from `sensors/mpu9250/`)
- `ak8963_handler.py` (from `sensors/mpu9250/`)
- `mpu9250.py` (from `sensors/mpu9250/`)
- `mpu6500.py` (from `sensors/mpu9250/`)
- `ak8963.py` (from `sensors/mpu9250/`)
- `neo6mv2_handler.py` (from `sensors/gps/`)
- `camera_handler.py` (from `io/camera/`)
- `sdcard_handler.py` (from `io/sd-card/`)

All files should be in the root directory of your Pico, or in the same folder.

### 5. Run
```python
# On Pico - execute main script
python vyomsat.py
```

Or set it as `main.py` to run automatically on boot.

### 6. Monitor & Test

**Startup:**
1. Watch USB console for initialization messages
2. Verify SD card initialization: `[OK] SD card initialized successfully!`
3. Verify camera initialization: `[OK] Camera initialized successfully!`
4. Verify GPS initialization: `[OK] GPS sensor initialized on UART1`
5. Verify 9-axis IMU initialization: `[OK] 9-axis IMU sensor initialized successfully!`
6. Check OLED display shows normal telemetry

**Photo-to-SD Testing:**
1. Wait for system to fully initialize
2. Send 'c' via UART (XBee)
3. Observe USB console for capture process
4. Watch OLED display for capture feedback (3 seconds)
5. Observe USB console for SD transfer process
6. Watch OLED display for transfer feedback (2 seconds)
7. Receive final ACK via UART
8. **Remove SD card and verify image on computer**
9. **Verify original file deleted from Pico flash**
10. Capture multiple photos to test auto-increment

**Test Command 'c':**
1. Send 'c' via UART
2. Watch OLED show "Capturing..."
3. Observe USB console showing image capture
4. OLED displays success with filename (3 seconds)
5. Watch OLED show "Moving to SD card..."
6. Observe USB console showing file transfer
7. OLED displays "Moved to SD!" with filename (2 seconds)
8. Receive final ACK via UART: "Image saved to SD card"
9. Remove SD card and verify image file exists
10. Check image opens correctly on computer
11. Verify original file NOT on Pico flash
12. Repeat to test multiple sequential captures

**Normal Operation:**
- **USB Console**: Monitor debug output with telemetry and photo capture status (115200 baud)
- **OLED**: View real-time telemetry (battery, GPS position)
- **XBee**: Receive telemetry stream and send commands
- **SD Card**: Store captured images and sensor data logs
- **Pico Flash**: Freed after each photo transfer

## Configuration

Key constants in `vyomsat.py`:

```python
# OLED Display
OLED_SCL_PIN = 7              # I2C clock pin
OLED_SDA_PIN = 6              # I2C data pin

# Battery Monitoring
BATTERY_ADC_CHANNEL = 2                    # ADC2 (GP28)
BATTERY_VOLTAGE_DIVIDER_FACTOR = 0.5       # 2:1 voltage divider

# UART Communication (XBee)
UART_BAUDRATE = 9600          # Standard XBee baudrate
UART_TX_PIN = 0               # GP0
UART_RX_PIN = 1               # GP1

# XBee Reset
XBEE_RESET_PIN = 2            # GP2
XBEE_INIT_DELAY_SECONDS = 5   # Boot delay

# 9-Axis IMU Sensor
NINE_AXIS_SCL_PIN = 21        # GPIO 21 for I2C Serial Clock
NINE_AXIS_SDA_PIN = 20        # GPIO 20 for I2C Serial Data
NINE_AXIS_I2C_FREQ = 400000   # I2C bus frequency (400kHz)

# GPS Sensor
GPS_UART_ID = 1               # UART1 interface
GPS_TX_PIN = 4                # GPIO 4 for UART1 TX
GPS_RX_PIN = 5                # GPIO 5 for UART1 RX
GPS_BAUDRATE = 9600           # NEO-6M default baudrate
GPS_TIMEZONE_OFFSET = 4       # Dubai/UAE timezone (UTC+4)

# SD Card Module
SD_CS_PIN = 13                # GPIO 13 for Chip Select
SD_SCK_PIN = 10               # GPIO 10 for Serial Clock (SPI1)
SD_MOSI_PIN = 11              # GPIO 11 for Master Out Slave In (SPI1)
SD_MISO_PIN = 12              # GPIO 12 for Master In Slave Out (SPI1)
SD_SPI_ID = 1                 # SPI1 interface
SD_BAUDRATE = 1000000         # 1 MHz SPI baudrate

# Telemetry Rate
MAIN_LOOP_DELAY_SECONDS = 4   # Update interval
```

## Understanding Photo-to-SD Operation

### File Transfer Process

The photo-to-SD transfer happens in several stages:

| Stage | Duration | Action | Purpose |
|---|---|---|---|
| **Camera Capture** | 3-5 seconds | Capture JPEG to flash | Create image file |
| **Flash Storage** | < 1 second | Save with auto-increment | Temporary storage |
| **SD Check** | < 1 second | Verify SD availability | Ensure destination ready |
| **File Copy** | 1-2 seconds | Copy to SD card | Permanent storage |
| **Flash Cleanup** | < 1 second | Delete original | Free memory |

### Storage Management

**Pico Flash Memory:**
- Temporary storage during capture
- Original files deleted after SD transfer
- Freed for next photo or system operations
- No long-term storage burden

**SD Card Storage:**
- Permanent storage for all images
- Organized at root level: /sd/vyomsat_image_XXX.jpg
- Auto-incremented filenames preserved
- Centralized with sensor data logs

### File Naming Convention

Images maintain their auto-incremented names:
- Format: `vyomsat_image_XXX.jpg`
- Counter starts at 000
- Increments with each capture
- Example sequence: vyomsat_image_000.jpg, vyomsat_image_001.jpg, vyomsat_image_002.jpg
- Names preserved when moved to SD card

### Storage Capacity Planning

| SD Card Size | Estimated Images* | Sensor Logs** | Total Capacity |
|---|---|---|---|
| **2GB** | ~2,500 - 10,000 | ~400,000 | Mixed storage |
| **8GB** | ~10,000 - 40,000 | ~1,600,000 | Mixed storage |
| **16GB** | ~20,000 - 80,000 | ~3,200,000 | Mixed storage |
| **32GB** | ~40,000 - 160,000 | ~6,400,000 | Mixed storage |

*Image size varies: 200KB-800KB depending on scene complexity  
**Sensor log size: ~2-5KB per log

## Troubleshooting

| Issue | Solution |
|---|---|
| **Photo captured but not on SD** | Check SD card initialization status |
| | Verify USB console shows "File copied to SD card" |
| | Ensure SD card not full |
| | Check SD card not write-protected |
| **Original file not deleted** | Normal if deletion warning shown |
| | Photo still successfully on SD card |
| | Manually delete from Pico if needed |
| **SD transfer fails** | Photo remains on Pico flash |
| | Check SD card availability |
| | Verify SD card has free space |
| | Try removing and reinserting SD card |
| **OLED stuck on "Moving to SD..."** | Wait for timeout or restart system |
| | Check USB console for error details |
| | Verify SD card properly inserted |
| **Multiple photos exhausting Pico flash** | SD card not transferring properly |
| | Manually delete old photos from flash |
| | Check SD card initialization |
| **SD card full** | Transfer card contents to computer |
| | Delete old photos/logs from SD card |
| | Use larger capacity SD card |
| **Image corrupted on SD** | Check power supply stability |
| | Verify SD card is not faulty |
| | Try different SD card |
| | Ensure transfer completes before removal |
| **Auto-increment counter resets** | Normal after flash memory cleared |
| | File manager tracks highest number |
| | Existing files on SD not overwritten |
| **Camera still working?** | Yes - camera independent of SD |
| | Photos saved to flash if SD unavailable |
| | Manual transfer required if SD fails |
| **Sensor logging still working?** | Yes - all subsystems remain operational |
| | Command 's' still logs sensor data |
| | Images and logs share SD card peacefully |

## Technical Details

### Communication Interfaces Summary

| Interface | Pins | Speed | Address/Config | Purpose |
|---|---|---|---|---|
| SPI0 | GP16/17/18/19 | 8 MHz | Bus ID 0 | ArduCam Mega camera |
| SPI1 | GP10/11/12/13 | 1 MHz | Bus ID 1 | Micro SD Card module |
| UART0 | GP0/GP1 | 9600 bps | N81 | XBee communication |
| UART1 | GP4/GP5 | 9600 bps | N81 | GPS module |
| I2C0 | GP6/GP7 | 400 kHz | 0x3C | OLED Display |
| I2C1 | GP20/GP21 | 400 kHz | 0x68, 0x0C | MPU9250 IMU |

### Storage Workflow

```
┌─────────────────────────────────────────┐
│ Command 'c' Received                    │
└────────────────┬────────────────────────┘
                 ↓
┌─────────────────────────────────────────┐
│ Camera Capture                          │
│ - Capture 3MP JPEG image                │
│ - Save to Pico flash memory             │
│ - Filename: vyomsat_image_XXX.jpg       │
└────────────────┬────────────────────────┘
                 ↓
┌─────────────────────────────────────────┐
│ Automatic SD Transfer                   │
│ - Check SD card availability            │
│ - Copy file to /sd/                     │
│ - Preserve filename                     │
│ - Delete original from flash            │
└────────────────┬────────────────────────┘
                 ↓
┌─────────────────────────────────────────┐
│ Result                                  │
│ - Image stored on SD card               │
│ - Pico flash memory freed               │
│ - ACK sent via UART                     │
│ - System ready for next capture         │
└─────────────────────────────────────────┘
```

### Image Specifications

- **Format**: JPEG compressed
- **Resolution**: 3MP (2048x1536 pixels)
- **Sensor**: OV5642 CMOS
- **File Size**: 200KB-800KB (varies by scene)
- **Storage**: SD card (/sd/ directory)
- **Naming**: Auto-incremented (vyomsat_image_XXX.jpg)

### Timing in Main Loop

The main loop includes strategic timing to prevent bus contention:
- **100ms delay**: Prevents GPS UART from interfering with I2C
- **1-second pause**: After operations before resuming telemetry
- **Photo capture**: Temporarily pauses main loop (3-5 seconds)
- **Photo transfer**: Additional 1-2 seconds for SD copy
- **Total command 'c' time**: ~7-10 seconds including OLED displays

## Changes from Step 4

### Software Enhancements
- ✅ Enhanced `vyomsat.py` - Automatic photo-to-SD transfer in command 'c'
- ✅ Enhanced `vyomsat_sd_manager.py` - New `move_file_to_sd()` function
- ✅ File management - Automatic cleanup of Pico flash after transfer
- ✅ OLED feedback - Transfer status displays
- ✅ UART responses - Complete workflow acknowledgments

### Functional Improvements
- ✅ Automatic image transfer to SD card after capture
- ✅ Flash memory freed immediately after each photo
- ✅ Original filenames preserved on SD card
- ✅ Enhanced OLED feedback for complete capture-transfer workflow
- ✅ Improved UART messaging for photo-to-SD operation
- ✅ Graceful degradation when SD card unavailable
- ✅ Error handling for transfer failures
- ✅ Centralized storage management (images + logs on SD)

### Mission Benefits
- ✅ **Extended Mission Duration**: More photos possible without flash exhaustion
- ✅ **Simplified Data Retrieval**: Single SD card contains all mission data
- ✅ **Automated Workflow**: No manual file management required
- ✅ **Storage Efficiency**: Pico flash preserved for critical operations
- ✅ **Operational Reliability**: Graceful handling of SD card issues

## Testing Procedure

### 1. Hardware Verification
- [ ] All connections secure and correct
- [ ] SD card module positioned properly
- [ ] SD card inserted in module
- [ ] **SD card formatted as FAT32 with free space**
- [ ] SPI1 wiring verified (SCK, MISO, MOSI, CS)
- [ ] Camera module wired correctly to SPI0
- [ ] Common ground connected to all modules

### 2. Software Verification
- [ ] All required libraries uploaded to Pico
- [ ] sdcard_handler.py present on Pico
- [ ] camera_handler.py present on Pico
- [ ] Main script runs without errors
- [ ] USB console shows successful initialization

### 3. Camera Initialization Testing
- [ ] Camera initialization message: `[OK] Camera initialized successfully!`
- [ ] SD card initialization message: `[OK] SD card initialized successfully!`
- [ ] No SPI errors during startup
- [ ] Both SPI buses operational

### 4. Command 'c' Testing (Photo Capture)
- [ ] Send 'c' via UART
- [ ] USB console shows capture process
- [ ] OLED displays "Capturing..."
- [ ] OLED shows success with filename (3 seconds)
- [ ] Image filename displayed correctly

### 5. Photo-to-SD Transfer Testing
- [ ] After capture, OLED shows "Moving to SD..."
- [ ] USB console shows file transfer process
- [ ] File copy to SD card succeeds
- [ ] Original file deleted from Pico flash
- [ ] OLED shows "Moved to SD!" with filename (2 seconds)
- [ ] UART receives final ACK: "Image saved to SD card"

### 6. Image Verification
- [ ] Remove SD card safely
- [ ] Insert SD card in computer
- [ ] Image file exists at root: vyomsat_image_XXX.jpg
- [ ] Filename matches auto-increment counter
- [ ] Image file opens successfully
- [ ] Image quality acceptable
- [ ] File size reasonable (200KB-800KB)

### 7. Multi-Photo Testing
- [ ] Capture multiple photos sequentially
- [ ] Each photo auto-increments correctly
- [ ] All photos appear on SD card
- [ ] No photos remain on Pico flash
- [ ] System stable across multiple captures
- [ ] SD card storage not exhausted

### 8. Error Handling Testing
- [ ] Remove SD card and capture photo
- [ ] System handles SD unavailability gracefully
- [ ] Photo remains on Pico flash
- [ ] NAK sent when SD transfer fails
- [ ] Error messages displayed on OLED
- [ ] System continues operating normally
- [ ] Next capture works after SD card reinserted

### 9. Integration Testing
- [ ] Battery voltage displays correctly
- [ ] GPS continues working during photo capture
- [ ] Command 's' (sensor logging) still functional
- [ ] Command 'a' (9-axis) still functional
- [ ] Command 'g' (GPS) still functional
- [ ] OLED returns to telemetry after capture
- [ ] UART telemetry resumes normally
- [ ] All subsystems work together without conflicts

### 10. Storage Management Testing
- [ ] Check Pico flash after multiple captures
- [ ] Verify no old photos accumulating
- [ ] Check SD card free space decreasing appropriately
- [ ] Verify filenames don't conflict
- [ ] Test with near-full SD card
- [ ] Verify error handling when SD card full

## License

MIT License - Copyright (c) 2025 Ojas Jha

See individual Python files for full license text.

## Author

**Ojas Jha**  
VyomSat CubeSat Education Kit  
Date: October 25, 2025

## Acknowledgments

- Steps 0-4 (EPS, COM, 9-Axis, GPS, Camera, SD Card) provide the foundation
- Enhanced camera-to-SD integration for mission efficiency
- Automated file management for extended mission duration
- ArduCam Mega 3MP camera with JPEG compression
- Micro SD Card Module with FAT32 filesystem support
- Fritzing diagrams created with Fritzing open-source software

## References

- MicroPython SD Card Driver Documentation
- ArduCam Mega Camera Documentation
- SD Card Association: SD/SDHC Specifications
- FAT Filesystem Documentation
- Raspberry Pi Pico SPI Documentation
- MicroPython File I/O Reference
- Image Storage Best Practices for Embedded Systems

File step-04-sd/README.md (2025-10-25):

# VyomSat Step 4: EPS + COM + 9-Axis IMU + GPS + Camera + SD Card Integration

**VyomSat - Essence of Space. Built by You.**

This step builds upon Step 3 (EPS + COM + 9-Axis IMU + GPS + Camera) by adding SD card data logging capabilities. The system now provides comprehensive data storage for all sensor telemetry, enabling long-term mission data recording and analysis.

## Overview

Step 4 extends the camera imaging system with SD card storage for comprehensive sensor data logging. The system continuously measures battery voltage, communicates via UART, provides comprehensive attitude data through the MPU9250 IMU, tracks precise geographic location using GPS satellites, captures high-quality images on command, and now logs all sensor data to SD card for later analysis.

**New in Step 4:**
- 💾 **Micro SD Card Module** - SPI-based data logging to SD card
- 📝 **Multi-Sensor Data Logging** - Records housekeeping, 9-axis IMU, and GPS data
- 🔄 **Multi-Cycle Capture** - Collects data over 5 cycles with configurable timing
- 📊 **Timestamped Log Files** - Auto-generated filenames with Unix timestamps
- 🎯 **Command 's'** - Real-time sensor data logging to SD card
- 📺 **Enhanced Display** - OLED feedback during logging operations
- 💿 **FAT32 Filesystem** - Standard SD/SDHC card support (up to 32GB)

**Retained from Step 3:**
- 📷 ArduCam Mega 3MP Camera with JPEG capture
- 🖼️ Auto-incremented image filenames
- 🎯 Command 'c' for camera capture

**Retained from Step 2:**
- 🛰️ NEO-6M GPS Module with position tracking
- 📍 Location Data (latitude, longitude, altitude)
- 🕐 GPS Time & Date with timezone conversion
- 🎯 Command 'g' for GPS data capture

**Retained from Step 1:**
- 🧭 MPU9250 9-Axis IMU (accelerometer, gyroscope, magnetometer)
- 📊 Attitude Data (pitch, roll, heading)
- 🎯 Command 'a' for 9-axis data capture

**Retained from Step 0:**
- 📊 Battery Voltage Monitoring
- 📺 OLED Display (128x64 SSD1306)
- 📡 UART Communication (XBee)
- 🎛️ Command Interface
- ⚡ Hardware Reset Management

## Features

### SD Card Data Logging Capabilities

The Micro SD Card module provides comprehensive data storage:

- **Multi-Sensor Data Logging**: Comprehensive telemetry capture
  - Housekeeping Data: Battery voltage, timestamps, system uptime
  - 9-Axis IMU Data: Accelerometer, gyroscope, magnetometer, attitude, heading
  - GPS Data: Position, altitude, time, satellites, motion, fix quality
  - Multi-cycle collection: 5 cycles by default (configurable)
  - Cycle timing: 500ms delay between cycles (configurable)

- **File Management**: Automatic timestamped logs
  - Auto-generated filenames: sensor_log_[timestamp].txt
  - Unix timestamp for unique identification
  - Organized text format for easy parsing
  - Complete header and footer sections

- **SPI Communication**: High-speed SD card access
  - SPI Bus 1: 1 MHz communication speed (safe initialization)
  - 4-wire interface: SCK, MISO, MOSI, CS
  - Dedicated chip select for SD card control
  - FAT filesystem mounting

- **Card Compatibility**: Wide range of SD cards
  - SDSC (Standard Capacity): Up to 2GB, FAT16
  - SDHC (High Capacity): 2GB to 32GB, FAT32
  - Recommended: FAT32 formatted cards

### SD Card Integration Features

- **Command-Triggered Logging**: Data logging via command 's'
- **OLED Status Display**: Real-time feedback during logging
- **UART Acknowledgments**: ACK/NAK responses for success/failure
- **USB Console Logging**: Detailed logging status messages
- **Error Handling**: Graceful degradation if SD card unavailable
- **Multi-Screen Feedback**: OLED shows logging progress and results

### Data Log Format

Each log file contains comprehensive sensor data organized by cycle:

```
======================================================================
VyomSat Sensor Data Log
======================================================================
Log created: [Unix timestamp]
Number of cycles: 5
======================================================================

=== CYCLE 1 - HOUSEKEEPING DATA ===
Timestamp: [ms]
Time: HH:MM:SS
Battery Voltage: X.XX V

=== CYCLE 1 - MPU9250 9-AXIS IMU DATA ===
Timestamp: [ms]
Temperature: XX.XX C

ACCELEROMETER (m/s^2):
  X: X.XXX  Y: X.XXX  Z: X.XXX
  Magnitude: X.XXX m/s^2

GYROSCOPE (deg/s):
  X: X.XX  Y: X.XX  Z: X.XX
  Magnitude: X.XX deg/s

MAGNETOMETER (uT):
  X: X.XX  Y: X.XX  Z: X.XX
  Magnitude: X.XX uT

ATTITUDE (FILTERED):
  Pitch: X.XX deg
  Roll:  X.XX deg
  Heading: X.X deg (Magnetic North)

=== CYCLE 1 - GPS DATA ===

POSITION:
  Latitude: XX.XXXX° N/S
  Longitude: XX.XXXX° E/W
  Altitude: XXX.X m
  Geoid Height: XX.X m

TIME & DATE:
  GPS Time (local): HH:MM:SS.SS
  Date: DD/MM/YYYY
  Timezone Offset: +X h

MOTION:
  Course/Heading: XXX.X deg
  Compass Direction: [N/S/E/W/NE/etc]
  Speed (km/h): XX.XX km/h
  Speed (knots): XX.XX knots

SATELLITES:
  In View: XX
  In Use: XX
  Used IDs: [list]

FIX QUALITY:
  Fix Status (GGA): [status]
  Fix Type (GSA): [type]
  HDOP: X.XX
  VDOP: X.XX
  PDOP: X.XX

----------------------------------------------------------------------

[Cycles 2-5 repeat the same structure]

======================================================================
End of Log
======================================================================
```

## Hardware Requirements

### Components

- Raspberry Pi Pico 2 or Pico W
- SSD1306 OLED Display (128x64 pixels, I2C)
- MPU9250 9-Axis IMU Sensor Module (I2C)
- NEO-6M GPS Module (UART)
- ArduCam Mega 3MP SPI Camera Module (OV5642)
- **Micro SD Card Module (SPI)** ← **NEW**
- **Micro SD Card (FAT32, up to 32GB)** ← **NEW**
- XBee module (or compatible UART device)
- Battery voltage divider circuit
- 4.7kΩ pull-up resistors for I2C lines (2x for IMU)

### Wiring Connections

| Component | Pico Pin | Description |
|---|---|---|
| **OLED Display** | | |
| SCL | GP7 | I2C Serial Clock |
| SDA | GP6 | I2C Serial Data |
| VCC | 3.3V | Power |
| GND | GND | Ground |
| **MPU9250 9-Axis IMU** | | |
| SCL | GP21 | I2C Serial Clock |
| SDA | GP20 | I2C Serial Data |
| VCC | 3.3V | Power |
| GND | GND | Ground |
| **NEO-6M GPS Module** | | |
| TX (GPS → Pico) | GP5 | UART1 Receive |
| RX (Pico → GPS) | GP4 | UART1 Transmit |
| VCC | 3.3V | Power |
| GND | GND | Ground |
| **ArduCam Mega 3MP** | | |
| SCK | GP18 | SPI0 Serial Clock |
| MISO | GP16 | SPI0 Master In Slave Out |
| MOSI | GP19 | SPI0 Master Out Slave In |
| CS | GP17 | SPI0 Chip Select |
| VCC | 3.3V or 5V | Power (check module specs) |
| GND | GND | Ground |
| **Micro SD Card Module** | | **NEW** |
| SCK | GP10 | SPI1 Serial Clock |
| MISO | GP12 | SPI1 Master In Slave Out |
| MOSI | GP11 | SPI1 Master Out Slave In |
| CS | GP13 | SPI1 Chip Select |
| VCC | 3.3V or 5V | Power (module has regulator) |
| GND | GND | Ground |
| **XBee Module** | | |
| TX (Pico → XBee) | GP0 | UART0 Transmit |
| RX (XBee → Pico) | GP1 | UART0 Receive |
| RST | GP2 | Hardware Reset (optional) |
| GND | GND | Common Ground |
| **Battery Sensing** | | |
| ADC Input | GP28 | Battery voltage via divider |

> **Important Notes**: 
> - The SD Card Module uses SPI1 communication at 1 MHz (safe initialization speed)
> - SD card should be formatted as FAT32 for best compatibility
> - SPI Bus 0 (GP16/GP17/GP18/GP19) is dedicated to camera
> - SPI Bus 1 (GP10/GP11/GP12/GP13) is dedicated to SD card
> - UART1 (GP4/GP5) remains for GPS communication
> - UART0 (GP0/GP1) remains for XBee communication
> - The MPU9250 requires 4.7kΩ pull-up resistors on both SCL and SDA lines
> - Battery voltage must be reduced to 0-3.3V range using a voltage divider circuit
> - SD card module typically includes level shifters for 5V compatibility

### Circuit Diagrams

Visual references for hardware setup are provided using Fritzing diagrams:

#### Schematic Diagram
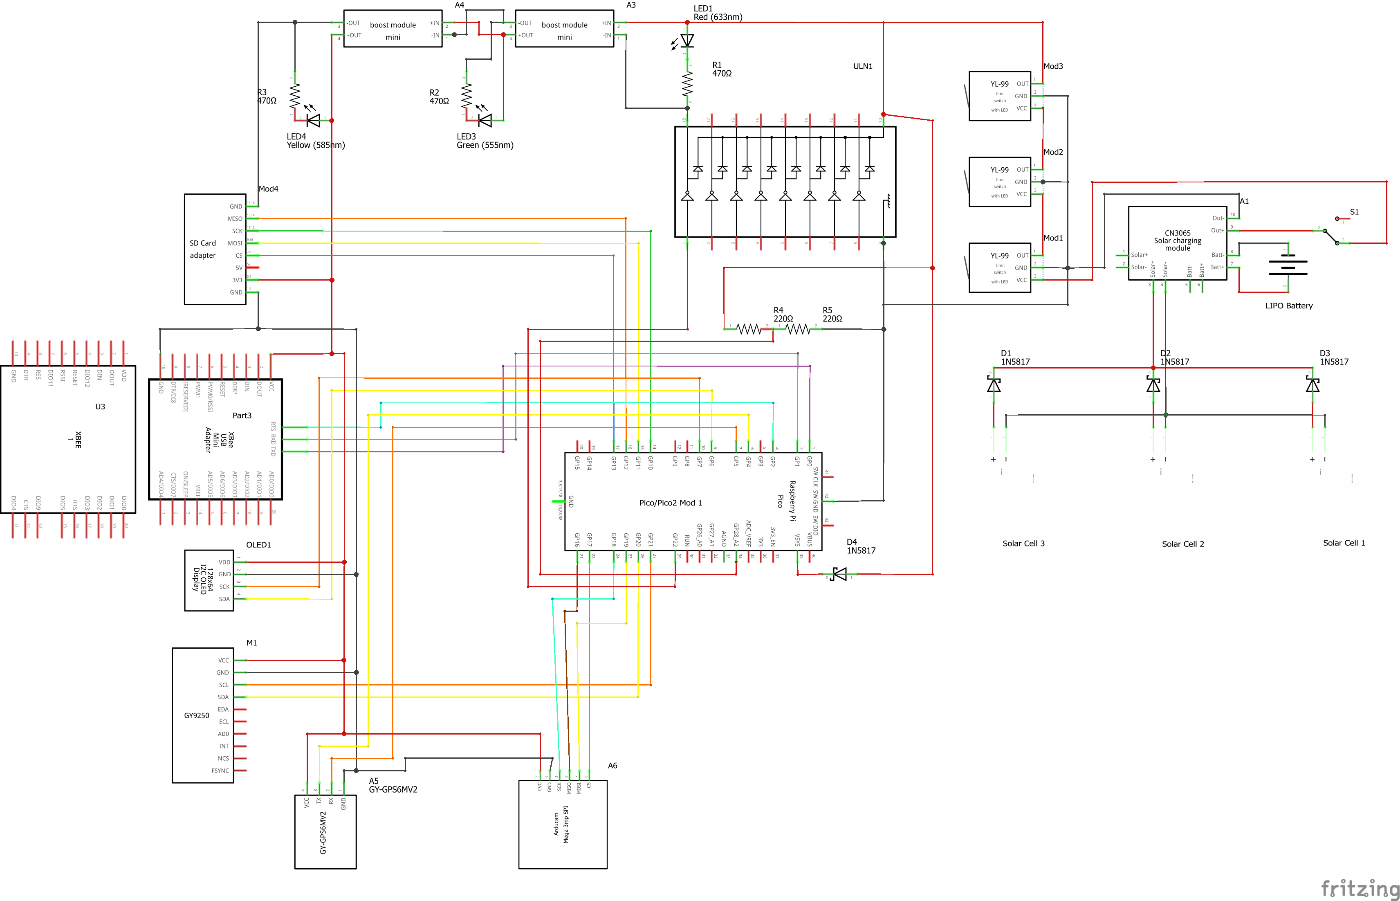
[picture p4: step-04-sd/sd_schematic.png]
VyomSat SD Card Schematic


The schematic shows the complete electrical connections including:
- Solar panel array with charge controller (CN3065)
- Multiple power rails (3.3V, 5V) with boost/buck converters
- Raspberry Pi Pico/Pico2 connections
- OLED display I2C interface (GP6/GP7)
- MPU9250 9-axis IMU I2C interface (GP20/GP21)
- NEO-6M GPS module UART1 interface (GP4/GP5)
- ArduCam Mega 3MP SPI0 interface (GP16/GP17/GP18/GP19)
- Micro SD Card Module SPI1 interface (GP10/GP11/GP12/GP13)
- XBee communication module on UART0 (GP0/GP1)
- Battery voltage sensing circuit
- LED status indicators
- Limit switches for mission control
- Power management components

#### Breadboard Layout
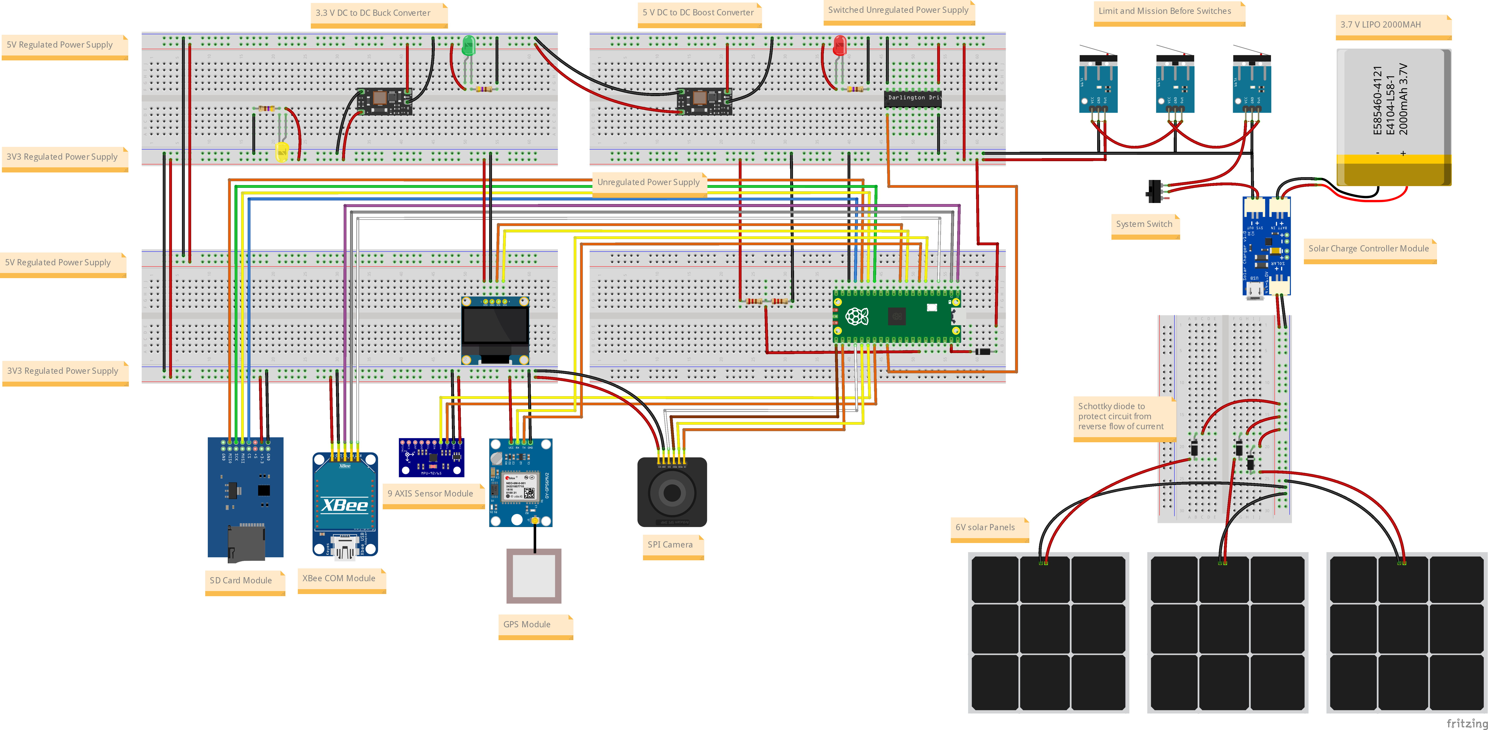
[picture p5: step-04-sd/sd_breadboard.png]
VyomSat SD Card Breadboard


The breadboard layout provides a practical wiring guide showing:
- Physical component placement
- Wire routing and connections
- Power distribution
- Module interconnections
- Camera module positioning and SPI0 connections
- SD card module positioning and SPI1 connections
- GPS module with antenna

#### Bill of Materials (BOM)
A complete parts list with quantities and specifications is available: **[sd_bom.html](sd_bom.html)**

The BOM includes all components from Steps 0, 1, 2, and 3 plus:
- Micro SD Card Module with SPI interface
- Level conversion support (5V or 3.3V)
- 42mm × 24mm × 12mm form factor
- Supports Micro SD (≤2GB) and Micro SDHC (≤32GB) cards
- All resistors, capacitors, ICs, and modules required

> **Fritzing Software**: These diagrams were created using [Fritzing](https://fritzing.org/), an open-source electronics design tool. Download from [fritzing.org/download](https://fritzing.org/download/) to view or modify the designs.

## Architecture

The system builds on Step 3's modular architecture with new SD card capabilities:

### New Module: `vyomsat_sd_manager.py`
Handles Micro SD Card data logging and filesystem operations.

**Key Functions:**
- `initialize_sd_card()`: Initializes SD card with SPI configuration and mounts filesystem
- `log_sensor_data_to_sd()`: Logs comprehensive sensor data for specified number of cycles
- `log_and_display_sensor_data()`: Complete logging with OLED feedback and UART responses
- `is_sd_card_available()`: Checks if SD card is initialized and available
- `format_housekeeping_data()`: Formats battery and timestamp data for logging
- `format_9axis_data_for_logging()`: Formats MPU9250 IMU data for logging
- `format_gps_data_for_logging()`: Formats NEO-6M GPS data for logging

**How it works:**
- Initializes SPI Bus 1 for SD card communication (1 MHz on GPIO 10/11/12/13)
- Creates SD card driver and mounts FAT filesystem at `/sd`
- Generates timestamped filenames: `sensor_log_[timestamp].txt`
- Collects data over multiple cycles (default: 5 cycles, 500ms apart)
- Formats comprehensive sensor data in human-readable text format
- Writes organized log file with headers, data sections, and footers
- Provides OLED feedback during logging process
- Sends ACK/NAK responses via UART

**OLED Display Feedback:**
When command 's' is received, the system provides visual feedback:
1. **Logging Screen**: "SD Card" / "Logging..." / "X cycles" (during capture)
2. **Success Screen**: "SD Logging OK!" / "Data saved:" / filename (3 seconds)
3. **Error Screen**: "SD Error!" / error message (2 seconds)

**SD Card Settings:**
- SPI Bus: SPI1 (ID 1)
- Baudrate: 1 MHz (safe initialization speed)
- Polarity: 0 (clock idle LOW)
- Phase: 0 (data sampled on rising edge)
- Mount Point: `/sd`
- Filesystem: FAT16/FAT32

### Updated: `vyomsat.py`
Main integration module extended with SD card support.

**Changes from Step 3:**
- Added SD card sensor initialization in `main()` function
- Updated command 's' handler to call `log_and_display_sensor_data()`
- Added 1-second pause after SD logging before returning to telemetry
- Enhanced error handling for SD card unavailability
- Graceful degradation if SD card not available
- Documentation updated for SD card integration

**Operational Flow:**
```
┌─────────────────────────────────────────────┐
│ 1. Initialize Hardware                      │
│    - LED & GPIO pins                        │
│    - XBee hardware reset                    │
│    - Battery ADC sensor                     │
│    - 9-Axis IMU sensor                      │
│    - GPS sensor                             │
│    - Camera sensor                          │
│    - SD card module (NEW)                   │
│    - OLED display                           │
│    - UART communication                     │
└─────────────────────────────────────────────┘
                    ↓
┌─────────────────────────────────────────────┐
│ 2. Main Loop (every 4 seconds)             │
│    ┌─────────────────────────────────────┐ │
│    │ a. Read GPS data (non-blocking)     │ │
│    │ b. Read battery voltage             │ │
│    │ c. Get basic GPS data               │ │
│    │ d. Update OLED with GPS + HK        │ │
│    │ e. Send telemetry via UART (w/ GPS) │ │
│    │ f. Process incoming UART commands   │ │
│    │    - Command 's': SD card logging   │ │ ← NEW
│    │ g. Print status to USB console      │ │
│    └─────────────────────────────────────┘ │
└─────────────────────────────────────────────┘
```

### Retained Modules from Previous Steps

**`vyomsat_camera_manager.py`**: ArduCam Mega camera management (Step 3)  
**`vyomsat_gps_manager.py`**: NEO-6M GPS sensor management (Step 2)  
**`vyomsat_9axis_manager.py`**: MPU9250 9-axis IMU sensor management (Step 1)  
**`vyomsat_battery_manager.py`**: Battery voltage sensing via ADC (Step 0)  
**`vyomsat_oled_manager.py`**: SSD1306 OLED display management (Step 0)  
**`vyomsat_xbee_manager.py`**: XBee hardware reset handling (Step 0)

## Telemetry Output

### USB Serial Console - Normal Operation
```
[12345ms] Telemetry Sent | V: 6.90V | GPS: 25.2521, 55.3095 | Alt: 15.2m | Sats: 8 | Counter: 42
```

### USB Serial Console - SD Card Logging (Command 's')
```
UART Command Received: 's' (ASCII: 115)
Processing SD card data logging...
USB Response: Command 's' received: SD card logging initiated
SD Manager: Starting data logging to /sd/sensor_log_1729857309.txt
SD Manager: Collecting 5 cycles of sensor data...
SD Manager: Logging cycle 1/5...
SD Manager: Logging cycle 2/5...
SD Manager: Logging cycle 3/5...
SD Manager: Logging cycle 4/5...
SD Manager: Logging cycle 5/5...
[OK] SD Manager: Data logged: 5 cycles saved to sensor_log_1729857309.txt
[OK] SD logging SUCCESS: Data logged: 5 cycles saved to sensor_log_1729857309.txt
UART Response sent: 'ACK: Data logged: 5 cycles saved to sensor_log_1729857309.txt' (67 bytes)
```

### USB Serial Console - SD Card Error (Card Not Available)
```
UART Command Received: 's' (ASCII: 115)
Processing SD card data logging...
USB Response: Command 's' received: SD card logging initiated
[ERROR] SD logging FAILED: SD card not initialized
UART Response sent: 'NAK: SD card not available' (28 bytes)
```

### UART (XBee) - SD Logging Success
```
ACK: Data logged: 5 cycles saved to sensor_log_1729857309.txt
```

### UART (XBee) - SD Logging Failure
```
NAK: SD card not available
```

### OLED Display - SD Logging (Success)
```
SD Logging OK!
Data saved:
sensor_log_17298
57309.txt
```
(Displayed for 3 seconds, then returns to normal telemetry)

### OLED Display - SD Logging (Failure)
```
SD Card Error!
Not initialized
```
(Displayed for 2 seconds, then returns to normal telemetry)

### OLED Display - Normal Operation
```
VyomSat EPS+GPS
00:05:42
V: 6.90V
Lat:25.2521° N
Lon:55.3095° E
```

## Supported UART Commands

Send single character commands to control the system:

| Command | Function | Response | Status |
|---|---|---|---|
| `s` | **SD card data logging** | Comprehensive sensor log saved | **NEW** ✨ |
| `c` | Camera image capture | Image saved with filename | Active |
| `g` | GPS position data | Comprehensive GPS diagnostics | Active |
| `a` | 9-axis IMU attitude data | Comprehensive sensor data | Active |
| `v` | Request voltage reading | Detailed voltage data | Active |
| `b` | System reset | ACK (placeholder) | Reserved |

### Command 's' - SD Card Data Logging (NEW)

**Behavior:**
1. Checks if SD card is initialized and available
2. Displays "Logging..." on OLED with cycle count
3. Collects 5 cycles of sensor data (500ms between cycles)
4. Each cycle captures: housekeeping, 9-axis IMU, and GPS data
5. Writes comprehensive log file to SD card with timestamp
6. Shows progress bar during write operation
7. Displays success/failure on OLED (2-3 seconds)
8. Sends ACK/NAK response via UART with filename
9. Returns to normal telemetry display

**Example:**
```
Send: s

Receive (UART): ACK: SD card logging initiated
                ACK: Data logged: 5 cycles saved to sensor_log_1729857309.txt

Display (OLED): [SD logging sequence with feedback]

Storage: sensor_log_1729857309.txt saved to SD card
```

**SD Logging Process:**
1. Command 's' received via UART
2. SD card availability checked
3. OLED shows "Logging..." with cycle count
4. System collects data over 5 cycles
5. Each cycle: housekeeping → 9-axis → GPS
6. Log file created with Unix timestamp
7. Data written in organized text format
8. OLED shows "SD Logging OK!" + filename
9. UART sends ACK with filename
10. 1-second pause before returning to telemetry

**Data Collected Per Cycle:**
- **Housekeeping**: Battery voltage, timestamp, uptime
- **9-Axis IMU**: Accelerometer, gyroscope, magnetometer, attitude, heading, temperature
- **GPS**: Position, altitude, time/date, motion, satellites, fix quality, HDOP/VDOP/PDOP

### Command 'c' - Camera Image Capture

**Example:**
```
Send: c

Receive: ACK: Camera capture initiated
         ACK: Image saved as vyomsat_image_003.jpg
```

### Command 'g' - GPS Position Data

**Example:**
```
Send: g

Receive: ACK: GPS capture initiated
         [comprehensive GPS data follows]
```

### Command 'a' - 9-Axis Attitude Data

**Example:**
```
Send: a

Receive: ACK: MPU9250 capture initiated
         [comprehensive 9-axis IMU data follows]
```

### Command 'v' - Voltage Reading

**Example:**
```
Send: v

Receive: ACK: Battery voltage reading initiated
         [timestamp] BATTERY VOLTAGE | Batt: 6.900V | ADC: 3.450V | Raw: 32768
```

## Usage

### 1. Setup Hardware
Connect all components according to the wiring table above. Pay special attention to:
- Micro SD Card Module on SPI Bus 1 (GP10/11/12/13)
- SD card formatted as FAT32 (recommended)
- ArduCam Mega 3MP on SPI Bus 0 (GP16/17/18/19)
- NEO-6M GPS module on UART1 (GP4 TX, GP5 RX)
- 4.7kΩ pull-up resistors on MPU9250 I2C lines (SCL and SDA)
- Separate I2C buses for OLED (GP6/7) and IMU (GP20/21)
- Common ground connections for all modules

### 2. Prepare SD Card
- Format SD card as FAT32 (recommended for cards >2GB)
- FAT16 works for cards ≤2GB
- Ensure card is properly inserted in module before powering on

### 3. Get Required Libraries

The manager modules depend on sensor and breakout board libraries from the [OjasJha/micropython-lib](https://github.com/OjasJha/micropython-lib.git) repository.

Clone or download the repository:
```bash
git clone https://github.com/OjasJha/micropython-lib.git
```

**Required libraries for Step 4:**

*From Step 0:*
- `com/uart/uart_handler.py` - UART communication handler

*From Step 1:*
- `io/oled-ssd1306/ssd1306_handler.py` - SSD1306 OLED display driver
- `sensors/mpu9250/mpu9250_handler.py` - MPU9250 9-axis IMU handler
- `sensors/mpu9250/mpu6500_handler.py` - MPU6500 6-axis IMU handler
- `sensors/mpu9250/ak8963_handler.py` - AK8963 3-axis magnetometer handler
- `sensors/mpu9250/mpu9250.py` - Low-level MPU9250 driver
- `sensors/mpu9250/mpu6500.py` - Low-level MPU6500 driver
- `sensors/mpu9250/ak8963.py` - Low-level AK8963 driver

*From Step 2:*
- `sensors/gps/neo6mv2_handler.py` - NEO-6M GPS handler with NMEA parsing

*From Step 3:*
- `io/camera/camera_handler.py` - ArduCam Mega camera handler with JPEG capture

*NEW for Step 4:*
- `io/sd-card/sdcard_handler.py` - SD card driver for SPI-based SD/SDHC cards

> **Important**: Copy these library files directly to the same folder as the VyomSat modules (flat structure). Do NOT maintain the directory structure from the repository.

### 4. Upload Code

Copy all Python files to your Raspberry Pi Pico in the **same folder**:

**VyomSat Step 4 Modules:**
- `vyomsat.py` (updated)
- `vyomsat_battery_manager.py`
- `vyomsat_oled_manager.py`
- `vyomsat_xbee_manager.py`
- `vyomsat_9axis_manager.py`
- `vyomsat_gps_manager.py`
- `vyomsat_camera_manager.py`
- `vyomsat_sd_manager.py` ← **NEW**

**Libraries from micropython-lib repository:**
- `uart_handler.py` (from `com/uart/`)
- `ssd1306_handler.py` (from `io/oled-ssd1306/`)
- `mpu9250_handler.py` (from `sensors/mpu9250/`)
- `mpu6500_handler.py` (from `sensors/mpu9250/`)
- `ak8963_handler.py` (from `sensors/mpu9250/`)
- `mpu9250.py` (from `sensors/mpu9250/`)
- `mpu6500.py` (from `sensors/mpu9250/`)
- `ak8963.py` (from `sensors/mpu9250/`)
- `neo6mv2_handler.py` (from `sensors/gps/`)
- `camera_handler.py` (from `io/camera/`)
- `sdcard_handler.py` (from `io/sd-card/`) ← **NEW**

All files should be in the root directory of your Pico, or in the same folder.

### 5. Run
```python
# On Pico - execute main script
python vyomsat.py
```

Or set it as `main.py` to run automatically on boot.

### 6. Monitor & Test

**Startup:**
1. Watch USB console for initialization messages
2. Verify SD card initialization: `[OK] SD card initialized successfully!`
3. Verify camera initialization: `[OK] Camera initialized successfully!`
4. Verify GPS initialization: `[OK] GPS sensor initialized on UART1`
5. Verify 9-axis IMU initialization: `[OK] 9-axis IMU sensor initialized successfully!`
6. Check OLED display shows normal telemetry

**SD Card Testing:**
1. Wait for system to fully initialize
2. Send 's' via UART (XBee)
3. Observe USB console for logging process (5 cycles)
4. Watch OLED display for logging feedback
5. Receive ACK with filename via UART
6. Verify log file created on SD card
7. Read log file to verify data format

**Test Command 's':**
1. Send 's' via UART
2. Watch OLED show "Logging..." with cycle count
3. Observe USB console logging each cycle (1/5, 2/5, etc.)
4. Wait for 5 cycles to complete (~2.5 seconds)
5. OLED displays success with filename (3 seconds)
6. Receive ACK via UART with filename
7. Remove SD card and verify log file on computer
8. Check log file contains all sensor data sections

**Normal Operation:**
- **USB Console**: Monitor debug output with telemetry and SD logging status (115200 baud)
- **OLED**: View real-time telemetry (battery, GPS position)
- **XBee**: Receive telemetry stream and send commands
- **SD Card**: Log comprehensive sensor data on demand via command 's'

## Configuration

Key constants in `vyomsat.py`:

```python
# OLED Display
OLED_SCL_PIN = 7              # I2C clock pin
OLED_SDA_PIN = 6              # I2C data pin

# Battery Monitoring
BATTERY_ADC_CHANNEL = 2                    # ADC2 (GP28)
BATTERY_VOLTAGE_DIVIDER_FACTOR = 0.5       # 2:1 voltage divider

# UART Communication (XBee)
UART_BAUDRATE = 9600          # Standard XBee baudrate
UART_TX_PIN = 0               # GP0
UART_RX_PIN = 1               # GP1

# XBee Reset
XBEE_RESET_PIN = 2            # GP2
XBEE_INIT_DELAY_SECONDS = 5   # Boot delay

# 9-Axis IMU Sensor
NINE_AXIS_SCL_PIN = 21        # GPIO 21 for I2C Serial Clock
NINE_AXIS_SDA_PIN = 20        # GPIO 20 for I2C Serial Data
NINE_AXIS_I2C_FREQ = 400000   # I2C bus frequency (400kHz)

# GPS Sensor
GPS_UART_ID = 1               # UART1 interface
GPS_TX_PIN = 4                # GPIO 4 for UART1 TX
GPS_RX_PIN = 5                # GPIO 5 for UART1 RX
GPS_BAUDRATE = 9600           # NEO-6M default baudrate
GPS_TIMEZONE_OFFSET = 4       # Dubai/UAE timezone (UTC+4)

# SD Card Module (NEW)
SD_CS_PIN = 13                # GPIO 13 for Chip Select
SD_SCK_PIN = 10               # GPIO 10 for Serial Clock (SPI1)
SD_MOSI_PIN = 11              # GPIO 11 for Master Out Slave In (SPI1)
SD_MISO_PIN = 12              # GPIO 12 for Master In Slave Out (SPI1)
SD_SPI_ID = 1                 # SPI1 interface
SD_BAUDRATE = 1000000         # 1 MHz SPI baudrate

# Telemetry Rate
MAIN_LOOP_DELAY_SECONDS = 4   # Update interval
```

Key constants in `vyomsat_sd_manager.py`:

```python
# SPI Bus Configuration
SPI1_ID = 1
SPI1_SCK_PIN = 10             # Serial Clock (GP10)
SPI1_MISO_PIN = 12            # Master In Slave Out (GP12)
SPI1_MOSI_PIN = 11            # Master Out Slave In (GP11)
SPI1_BAUDRATE = 1000000       # 1 MHz

# SD Card Chip Select Pin
SD_CS_PIN = 13                # Chip Select (GP13)

# Filesystem Mount Point
MOUNT_POINT = '/sd'           # SD card mount directory

# Data Collection Configuration
DEFAULT_NUM_CYCLES = 5                    # Number of data cycles
DEFAULT_DELAY_BETWEEN_CYCLES_MS = 500     # 500ms between cycles
```

## Understanding SD Card Operation

### Data Logging Process

The SD card logs data through several stages:

| Stage | Duration | Action | Purpose |
|---|---|---|---|
| **Initialization** | One-time | Mount filesystem | Prepare SD card |
| **File Creation** | < 1 second | Generate filename | Create timestamped log |
| **Cycle 1** | ~500ms | Collect HK + 9-axis + GPS | First data point |
| **Cycles 2-5** | ~500ms each | Collect HK + 9-axis + GPS | Additional data points |
| **File Write** | 1-2 seconds | Write to SD card | Save complete log |

### Log File Naming

Log files are automatically timestamped:
- Format: `sensor_log_[unix_timestamp].txt`
- Example: `sensor_log_1729857309.txt`
- Each log is uniquely identified by creation timestamp
- Files never overwrite each other

### SD Card Specifications

| Setting | Value | Purpose |
|---|---|---|
| **Interface** | SPI1 | Dedicated bus for SD card |
| **Baudrate** | 1 MHz | Safe initialization speed |
| **Filesystem** | FAT16/FAT32 | Standard compatibility |
| **Card Type** | SDSC/SDHC | Up to 32GB capacity |
| **Mount Point** | /sd | Access path in filesystem |

### Data Collection Configuration

- **Number of Cycles**: 5 (configurable in code)
- **Cycle Delay**: 500ms (configurable in code)
- **Total Collection Time**: ~2.5 seconds for 5 cycles
- **Data Per Cycle**: Housekeeping + 9-Axis + GPS
- **File Format**: Human-readable text

## Troubleshooting

| Issue | Solution |
|---|---|
| **SD card not initializing** | Check wiring (SCK→GP10, MISO→GP12, MOSI→GP11, CS→GP13) |
| | Verify SD card is properly inserted |
| | Ensure SD card is formatted (FAT16 or FAT32) |
| | Try different SD card (some cards incompatible) |
| | Check module power supply (3.3V or 5V) |
| | Verify sdcard_handler.py library is uploaded |
| **Mounting fails** | Format SD card as FAT32 on computer |
| | Check card is not write-protected |
| | Verify card capacity (≤32GB for SDHC) |
| **Logging fails** | Check available space on SD card |
| | Verify SD card is properly initialized |
| | Ensure filesystem is mounted at /sd |
| | Monitor USB console for error messages |
| **No ACK received** | Verify UART connection to XBee |
| | Check command 's' is being received |
| | Monitor USB console for error messages |
| **OLED not updating** | Normal - OLED shows logging status briefly |
| | Returns to telemetry after completion |
| **Incomplete data in log** | Check sensor initialization (9-axis, GPS) |
| | Verify GPS has fix for complete data |
| | Ensure 9-axis IMU is responding |
| **SPI bus conflicts** | Camera on SPI0, SD card on SPI1 (separate buses) |
| | Verify pin assignments don't overlap |
| **GPS still working?** | Yes - GPS continues in background |
| | SD logging doesn't block GPS |
| **Camera still working?** | Yes - all subsystems remain operational |
| | Each command operates independently |
| **File not created** | Check SD card has write permission |
| | Verify filesystem is writable |
| | Ensure sufficient free space |

## Technical Details

### Communication Interfaces Summary

| Interface | Pins | Speed | Address/Config | Purpose |
|---|---|---|---|---|
| SPI0 | GP16/17/18/19 | 8 MHz | Bus ID 0 | ArduCam Mega camera |
| SPI1 | GP10/11/12/13 | 1 MHz | Bus ID 1 | Micro SD Card module |
| UART0 | GP0/GP1 | 9600 bps | N81 | XBee communication |
| UART1 | GP4/GP5 | 9600 bps | N81 | GPS module |
| I2C0 | GP6/GP7 | 400 kHz | 0x3C | OLED Display |
| I2C1 | GP20/GP21 | 400 kHz | 0x68, 0x0C | MPU9250 IMU |

### Storage Considerations

- **Log File Size**: ~2-5 KB per log (varies by data content and GPS fix)
- **SD Card Capacity**: Up to 32GB (SDHC), 2GB (SDSC)
- **Available Space**: Depends on card size
- **Log Capacity**: Thousands of logs on typical card
- **Recommendation**: Periodically transfer logs off card for long-term missions

### Timing in Main Loop

The main loop includes strategic timing to prevent bus contention:
- **100ms delay**: Prevents GPS UART from interfering with I2C
- **1-second pause**: After SD logging before resuming telemetry
- **SD logging**: Temporarily pauses main loop (3-5 seconds total)

## Changes from Step 3

### Hardware Additions
- ✅ Micro SD Card Module with SPI interface
- ✅ SPI Bus 1 interface (GP10/GP11/GP12/GP13) for SD card
- ✅ Chip select line (GP13) for SD card control
- ✅ Micro SD Card (FAT32 formatted, up to 32GB)

### Software Additions
- ✅ `vyomsat_sd_manager.py` - New module for SD card management
- ✅ SD card handler library (sdcard_handler.py)
- ✅ FAT filesystem mounting and management
- ✅ Command 's' implementation for data logging
- ✅ OLED feedback during SD logging operations
- ✅ Multi-sensor data formatting functions
- ✅ Timestamped log file generation

### Functional Improvements
- ✅ On-demand multi-sensor data logging via command interface
- ✅ Timestamped filename generation for unique logs
- ✅ Comprehensive text format for easy data analysis
- ✅ Multi-cycle data collection (5 cycles default)
- ✅ Real-time OLED feedback for SD card status
- ✅ ACK/NAK responses via UART with filenames
- ✅ Graceful degradation when SD card unavailable
- ✅ Comprehensive USB console logging for SD operations

## Testing Procedure

### 1. Hardware Verification
- [ ] All connections secure and correct
- [ ] SD card module positioned properly
- [ ] SD card inserted in module
- [ ] SD card formatted as FAT32
- [ ] SPI1 wiring verified (SCK, MISO, MOSI, CS)
- [ ] Common ground connected to all modules

### 2. Software Verification
- [ ] All required libraries uploaded to Pico
- [ ] sdcard_handler.py present on Pico
- [ ] Main script runs without errors
- [ ] USB console shows successful initialization

### 3. SD Card Initialization Testing
- [ ] SD card initialization message: `[OK] SD card initialized successfully!`
- [ ] No SPI errors during startup
- [ ] Filesystem mounted at `/sd`
- [ ] No mounting errors

### 4. Command 's' Testing
- [ ] Send 's' via UART
- [ ] USB console shows logging process (5 cycles)
- [ ] UART receives ACK with filename
- [ ] OLED shows logging feedback sequence
- [ ] Log file created on SD card
- [ ] Filename contains Unix timestamp

### 5. Log File Verification
- [ ] Log file exists on SD card
- [ ] File opens successfully on computer
- [ ] Contains proper header section
- [ ] All 5 cycles present in log
- [ ] Housekeeping data formatted correctly
- [ ] 9-axis IMU data present (if available)
- [ ] GPS data present (if available)
- [ ] Proper footer section

### 6. Multi-Logging Testing
- [ ] Log multiple times sequentially
- [ ] Each log has unique timestamp filename
- [ ] No file overwrites occur
- [ ] System stable across multiple logs
- [ ] Storage space not exhausted

### 7. Integration Testing
- [ ] Battery voltage displays correctly
- [ ] GPS continues working during SD logging
- [ ] Camera commands still functional
- [ ] 9-axis IMU commands still functional
- [ ] OLED returns to telemetry after logging
- [ ] UART telemetry resumes normally
- [ ] All subsystems work together without conflicts

### 8. Error Handling Testing
- [ ] SD card unavailable handled gracefully
- [ ] NAK sent when SD card not initialized
- [ ] Error messages displayed on OLED
- [ ] System continues operating if SD fails
- [ ] USB console shows meaningful error messages

## License

MIT License - Copyright (c) 2025 Ojas Jha

See individual Python files for full license text.

## Author

**Ojas Jha**  
VyomSat CubeSat Education Kit  
Date: October 25, 2025

## Acknowledgments

- Steps 0-3 (EPS, COM, 9-Axis, GPS, Camera) provide the foundation
- Micro SD Card Module with SPI interface
- SD card handler library based on MicroPython SPI SD card drivers
- FAT filesystem support from MicroPython VfsFat
- Fritzing diagrams created with Fritzing open-source software

## References

- MicroPython SD Card Driver Documentation
- SD Card Association: SD/SDHC Specifications
- FAT Filesystem Documentation
- Raspberry Pi Pico SPI Documentation
- MicroPython VfsFat Module Reference

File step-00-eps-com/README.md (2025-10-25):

# VyomSat Step 0: EPS + COM Integration

**VyomSat - Essence of Space. Built by You.**

This is the foundational step of the VyomSat CubeSat education kit, demonstrating battery voltage monitoring and communication capabilities through multiple interfaces.

## Overview

Step 0 implements a complete Electrical Power System (EPS) monitoring solution with communication capabilities. The system continuously measures battery voltage using the Raspberry Pi Pico's ADC and presents the data through three interfaces:
- **OLED Display** - Local visualization
- **USB Serial Console** - Development and debugging
- **XBee via UART** - Wireless telemetry

## Features

- 📊 **Battery Voltage Monitoring** - Real-time ADC-based voltage sensing with voltage divider support
- 📺 **OLED Display** - 128x64 SSD1306 display showing system status and telemetry
- 📡 **UART Communication** - Full-duplex XBee communication for telemetry and commands
- 🎛️ **Command Interface** - Remote command execution via UART
- ⚡ **Hardware Reset** - Synchronized XBee reset to prevent race conditions

## Hardware Requirements

### Components
- Raspberry Pi Pico 2 or Pico W
- SSD1306 OLED Display (128x64 pixels, I2C)
- XBee module (or compatible UART device)
- Battery voltage divider circuit

### Wiring Connections

| Component | Pico Pin | Description |
|---|---|---|
| **OLED Display** | | |
| SCL | GP7 | I2C Serial Clock |
| SDA | GP6 | I2C Serial Data |
| VCC | 3.3V | Power |
| GND | GND | Ground |
| **XBee Module** | | |
| TX (Pico → XBee) | GP0 | UART0 Transmit |
| RX (XBee → Pico) | GP1 | UART0 Receive |
| RST | GP2 | Hardware Reset (optional) |
| GND | GND | Common Ground |
| **Battery Sensing** | | |
| ADC Input | GP28 | Battery voltage via divider |

> **Note**: Battery voltage must be reduced to 0-3.3V range using a voltage divider circuit (default: 2:1 ratio allows measuring up to 6.6V).

### Circuit Diagrams

Visual references for hardware setup are provided using Fritzing diagrams:

#### Schematic Diagram
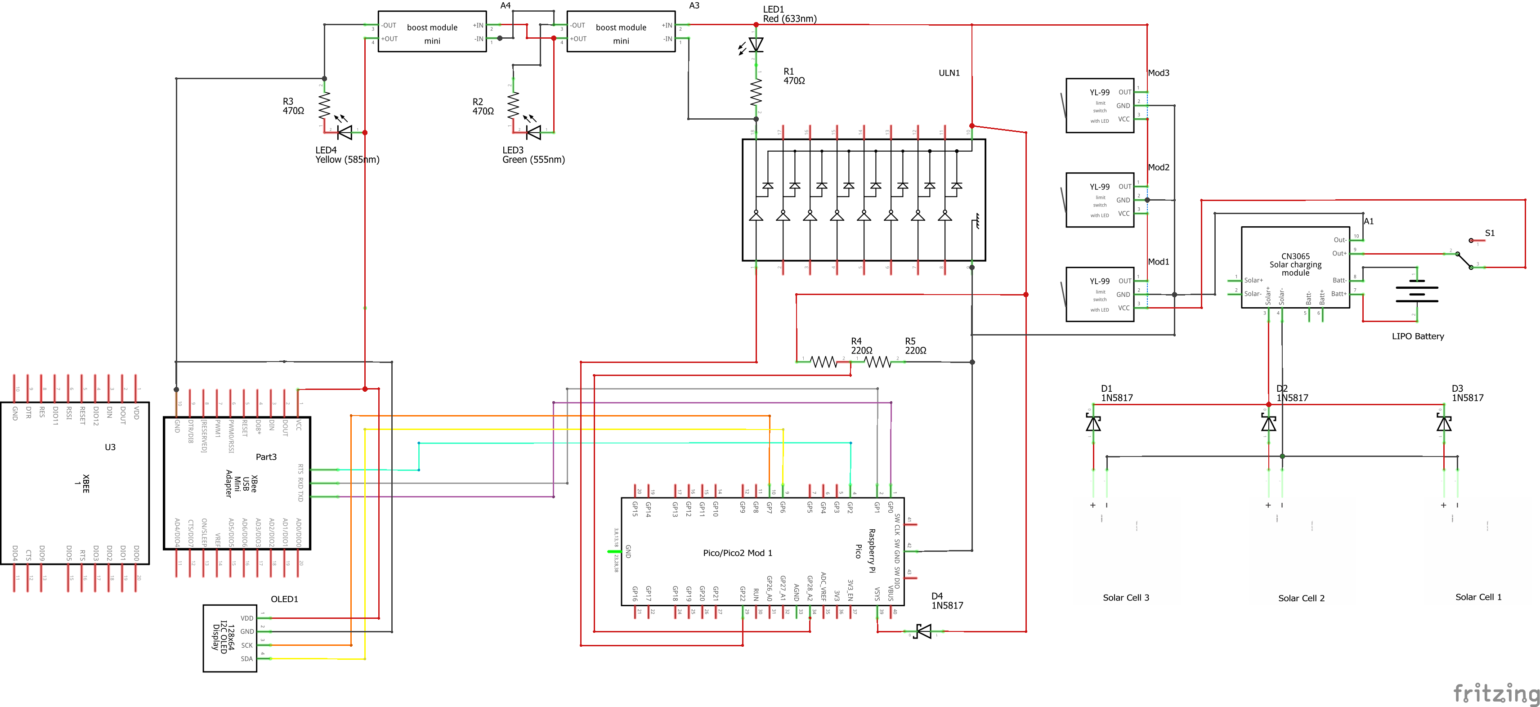
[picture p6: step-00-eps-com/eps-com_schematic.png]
VyomSat EPS+COM Schematic


The schematic shows the electrical connections including:
- Solar panel array with charge controller (CN3065)
- Multiple power rails (3.3V, 5V) with boost/buck converters
- Raspberry Pi Pico/Pico2 connections
- OLED display I2C interface
- XBee communication module
- Battery voltage sensing circuit
- LED status indicators
- Power management components

#### Breadboard Layout
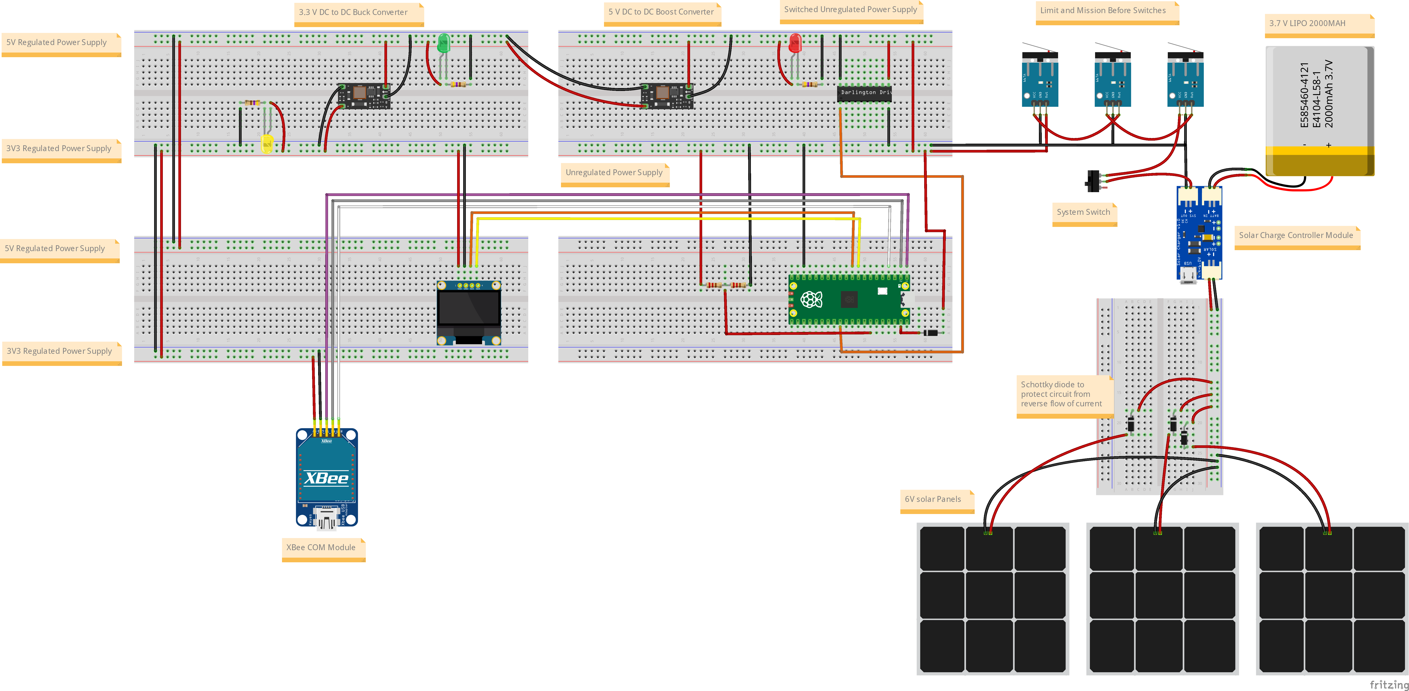
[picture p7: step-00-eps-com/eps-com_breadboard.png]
VyomSat EPS+COM Breadboard


The breadboard layout provides a practical wiring guide showing:
- Physical component placement
- Wire routing and connections
- Power distribution
- Module interconnections

#### Bill of Materials (BOM)
A complete parts list with quantities and specifications is available: **[eps-com_bom.html](eps-com_bom.html)**

The BOM includes:
- Complete component listing with labels and part numbers
- Shopping list with quantities needed
- Component specifications and properties
- All resistors, capacitors, ICs, and modules required

> **Fritzing Software**: These diagrams were created using [Fritzing](https://fritzing.org/), an open-source electronics design tool. You can download Fritzing from [fritzing.org/download](https://fritzing.org/download/) to view, edit, or create your own circuit diagrams.

## Architecture

The system is organized into modular components:

### 1. `vyomsat_battery_manager.py`
Handles battery voltage sensing through the RP2350's ADC.

**How it works:**
- Reads raw ADC value from GP28 (ADC2)
- Converts 16-bit reading (0-65535) to voltage (0-3.3V)
- Applies voltage divider correction to get actual battery voltage
- Provides multiple reading functions:
  - `read_battery_voltage()` - Corrected battery voltage
  - `read_adc_voltage()` - Raw ADC pin voltage
  - `read_raw_adc_value()` - Raw 16-bit ADC value

**Key Concept - Voltage Divider:**
```
Battery (+) → R1 → GP28 (ADC2) → R2 → GND

Vout = Vin × R2/(R1 + R2)
Battery Voltage = ADC Reading / Divider Factor
```

### 2. `vyomsat_oled_manager.py`
Manages the SSD1306 OLED display via I2C.

**Display Modes:**
- **Normal Mode** - Shows time, voltage, message counter, last received data
- **Command Mode** - Displays received commands with timestamp
- **Message Mode** - Shows received messages with length and timestamp

**How it works:**
- Creates I2C bus using software I2C (SoftI2C)
- Initializes SSD1306 display driver
- Provides methods to update display content
- Handles text rendering on 128x64 pixel screen (8 lines × 16 chars)

### 3. `vyomsat_xbee_manager.py`
Handles XBee module hardware reset.

**Purpose:**
Solves boot race condition where Pico boots faster than XBee. By performing a hardware reset after Pico initialization, ensures synchronized startup.

**Reset Sequence:**
1. RST pin HIGH (inactive)
2. Pull LOW for 100ms (active reset)
3. Release HIGH (XBee begins boot)
4. Wait 5 seconds for initialization

### 4. `vyomsat.py`
Main integration module that orchestrates all components.

**Operational Flow:**

```
┌─────────────────────────────────────────────┐
│ 1. Initialize Hardware                      │
│    - LED & GPIO pins                        │
│    - XBee hardware reset                    │
│    - Battery ADC sensor                     │
│    - OLED display                           │
│    - UART communication                     │
└─────────────────────────────────────────────┘
                    ↓
┌─────────────────────────────────────────────┐
│ 2. Main Loop (every 4 seconds)             │
│    ┌─────────────────────────────────────┐ │
│    │ a. Read battery voltage             │ │
│    │ b. Update OLED with telemetry       │ │
│    │ c. Send telemetry via UART          │ │
│    │ d. Process incoming UART commands   │ │
│    │ e. Print status to USB console      │ │
│    └─────────────────────────────────────┘ │
└─────────────────────────────────────────────┘
```

## Telemetry Output

### USB Serial Console
```
[12345ms] Telemetry Sent | Voltage: 6.90V | Bytes: 65 | Counter: 42
```

### UART (XBee)
```
[12345ms] VyomSat EPS | Voltage: 6.90V | Msg: #42
```

### OLED Display
```
VyomSat EPS
Time: 14:23:45
Batt: 6.90V
Msg: 42
```

## Supported UART Commands

Send single character commands to control the system:

| Command | Function | Response |
|---|---|---|
| `v` | Request voltage reading | Detailed voltage data |
| `a` | MPU6050 motion sensor | ACK (placeholder) |
| `b` | System reset | ACK (placeholder) |
| `c` | Camera capture | ACK (placeholder) |
| `s` | SD card logging | ACK (placeholder) |
| `g` | GPS data capture | ACK (placeholder) |

**Example:**
```
Send: v
Receive: ACK: Battery voltage reading initiated
         [timestamp] BATTERY VOLTAGE | Batt: 6.900V | ADC: 3.450V | Raw: 32768
```

## Usage

### 1. Setup Hardware
Connect all components according to the wiring table above.

### 2. Get Required Libraries
The manager modules depend on sensor and breakout board libraries from the [OjasJha/micropython-lib](https://github.com/OjasJha/micropython-lib.git) repository.

Clone or download the repository:
```bash
git clone https://github.com/OjasJha/micropython-lib.git
```

**Required libraries for Step 0:**
- `com/uart/uart_handler.py` - UART communication handler
- `io/oled-ssd1306/ssd1306_handler.py` - SSD1306 OLED display driver

> **Important**: Copy these library files directly to the same folder as the VyomSat modules (flat structure). Do NOT maintain the directory structure from the repository.

### 3. Upload Code
Copy all Python files to your Raspberry Pi Pico in the **same folder**:

**VyomSat Step 0 Modules:**
- `vyomsat.py`
- `vyomsat_battery_manager.py`
- `vyomsat_oled_manager.py`
- `vyomsat_xbee_manager.py`

**Libraries from micropython-lib repository:**
- `uart_handler.py` (from `com/uart/`)
- `ssd1306_handler.py` (from `io/oled-ssd1306/`)

All files should be in the root directory of your Pico, or in the same `step-00-eps-com/` folder.

### 4. Run
```python
# On Pico - execute main script
python vyomsat.py
```

Or set it as `main.py` to run automatically on boot.

### 5. Monitor
- **USB Console**: Connect serial terminal (115200 baud) to monitor debug output
- **OLED**: View real-time telemetry on display
- **XBee**: Receive telemetry stream and send commands

## Configuration

Key constants in `vyomsat.py`:

```python
# OLED Display
OLED_SCL_PIN = 7              # I2C clock pin
OLED_SDA_PIN = 6              # I2C data pin

# Battery Monitoring
BATTERY_ADC_CHANNEL = 2                    # ADC2 (GP28)
BATTERY_VOLTAGE_DIVIDER_FACTOR = 0.5       # 2:1 voltage divider

# UART Communication
UART_BAUDRATE = 9600          # Standard XBee baudrate
UART_TX_PIN = 0               # GP0
UART_RX_PIN = 1               # GP1

# XBee Reset
XBEE_RESET_PIN = 2            # GP2
XBEE_INIT_DELAY_SECONDS = 5   # Boot delay

# Telemetry Rate
MAIN_LOOP_DELAY_SECONDS = 4   # Update interval
```

## Troubleshooting

| Issue | Solution |
|---|---|
| No OLED display | Check I2C wiring (SCL→GP7, SDA→GP6) and power |
| OLED garbled text | Try I2C address 0x3D instead of 0x3C |
| No UART communication | Verify TX/RX connections and common ground |
| Incorrect voltage | Check voltage divider circuit and calibration |
| XBee not responding | Ensure reset pin is connected and working |

## Technical Details

### ADC Resolution
- **Hardware**: 12-bit ADC (0-4095)
- **MicroPython**: 16-bit reading (0-65535)
- **Reference**: 3.3V
- **Conversion Factor**: 3.3V / 65535 = 0.0000503540 V/count

### I2C Communication
- **Protocol**: Software I2C (SoftI2C)
- **Frequency**: 400 kHz (fast mode)
- **Address**: 0x3C (SSD1306 default)

### UART Communication
- **Baud Rate**: 9600 bps
- **Data Bits**: 8
- **Parity**: None
- **Stop Bits**: 1
- **Flow Control**: None

## License

MIT License - Copyright (c) 2025 Ojas Jha

See individual Python files for full license text.

## Author

**Ojas Jha**  
VyomSat CubeSat Education Kit  
Date: October 25, 2025

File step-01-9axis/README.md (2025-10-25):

# VyomSat Step 1: EPS + COM + 9-Axis IMU Integration

**VyomSat - Essence of Space. Built by You.**

This step builds upon Step 0 (EPS + COM) by adding 9-axis attitude sensing capabilities using the MPU9250 IMU sensor. The system now provides complete orientation and motion data for CubeSat applications.

## Overview

Step 1 extends the foundational Electrical Power System (EPS) monitoring and communication capabilities with a 9-axis Inertial Measurement Unit (IMU). The system continuously measures battery voltage, communicates via UART, and provides comprehensive attitude data through accelerometer, gyroscope, and magnetometer sensors.

**New in Step 1:**
- 🧭 **MPU9250 9-Axis IMU** - Complete attitude sensing with accelerometer, gyroscope, and magnetometer
- 📊 **Attitude Data Display** - Pitch, roll, and heading calculations with multi-screen OLED visualization
- 🎯 **Command 'a'** - Real-time attitude data capture and telemetry transmission
- 📈 **Sensor Fusion** - Complementary filter for accurate tilt angle estimation

**Retained from Step 0:**
- 📊 Battery Voltage Monitoring
- 📺 OLED Display (128x64 SSD1306)
- 📡 UART Communication (XBee)
- 🎛️ Command Interface
- ⚡ Hardware Reset Management

## Features

### 9-Axis IMU Capabilities

The MPU9250 provides complete 9-axis motion sensing:

- **3-Axis Accelerometer**: Linear acceleration measurement (m/s²)
  - Measures gravity and motion forces
  - Used for tilt angle calculation
  - Range: ±2g to ±16g (configurable)

- **3-Axis Gyroscope**: Angular velocity measurement (°/s)
  - Measures rotation rate
  - Used for motion detection and rate measurements
  - Range: ±250°/s to ±2000°/s (configurable)

- **3-Axis Magnetometer**: Magnetic field measurement (μT)
  - Earth's magnetic field sensing (compass)
  - Heading calculation (0-360°)
  - Range: ±4800 μT

- **Temperature Sensor**: On-chip temperature monitoring
  - Thermal compensation for sensors
  - Range: -40°C to +85°C

### Calculated Attitude Data

- **Pitch**: Forward/backward tilt angle (-90° to +90°)
- **Roll**: Left/right tilt angle (-180° to +180°)
- **Heading**: Compass direction (0° = North, 90° = East, 180° = South, 270° = West)
- **Sensor Fusion**: Complementary filter combining accelerometer and gyroscope data

## Hardware Requirements

### Components

- Raspberry Pi Pico 2 or Pico W
- SSD1306 OLED Display (128x64 pixels, I2C)
- MPU9250 9-Axis IMU Sensor Module (I2C)
- XBee module (or compatible UART device)
- Battery voltage divider circuit
- 4.7kΩ pull-up resistors for I2C lines (2x for IMU)

### Wiring Connections

| Component | Pico Pin | Description |
|---|---|---|
| **OLED Display** | | |
| SCL | GP7 | I2C Serial Clock |
| SDA | GP6 | I2C Serial Data |
| VCC | 3.3V | Power |
| GND | GND | Ground |
| **MPU9250 9-Axis IMU** | | |
| SCL | GP21 | I2C Serial Clock |
| SDA | GP20 | I2C Serial Data |
| VCC | 3.3V | Power |
| GND | GND | Ground |
| **XBee Module** | | |
| TX (Pico → XBee) | GP0 | UART0 Transmit |
| RX (XBee → Pico) | GP1 | UART0 Receive |
| RST | GP2 | Hardware Reset (optional) |
| GND | GND | Common Ground |
| **Battery Sensing** | | |
| ADC Input | GP28 | Battery voltage via divider |

> **Important Notes**: 
> - The MPU9250 requires 4.7kΩ pull-up resistors on both SCL and SDA lines for reliable I2C communication
> - The OLED and MPU9250 use separate I2C buses (different GPIO pins) to prevent conflicts
> - Battery voltage must be reduced to 0-3.3V range using a voltage divider circuit

### Circuit Diagrams

Visual references for hardware setup are provided using Fritzing diagrams:

#### Schematic Diagram
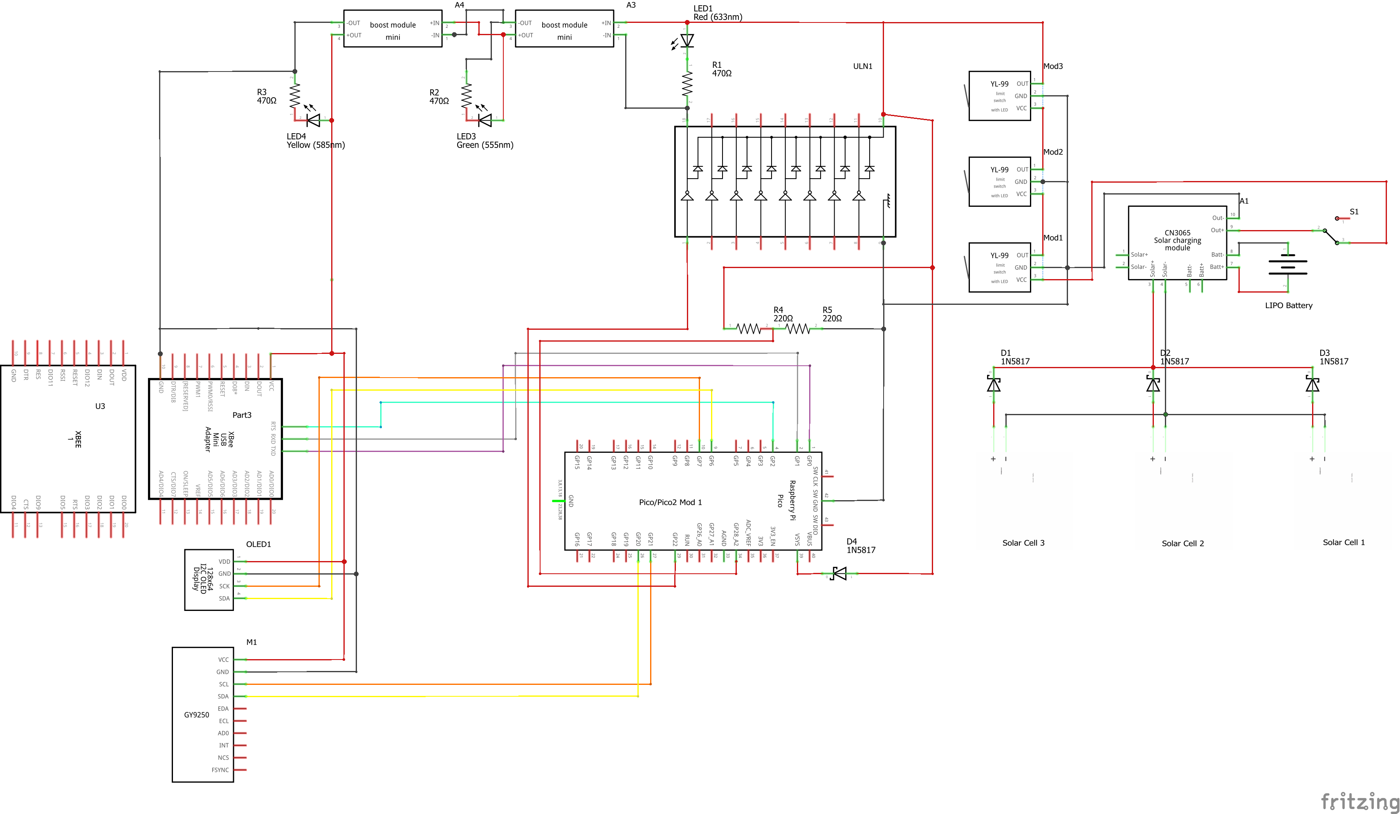
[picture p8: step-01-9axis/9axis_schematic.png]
VyomSat 9-Axis Schematic


The schematic shows the complete electrical connections including:
- Solar panel array with charge controller (CN3065)
- Multiple power rails (3.3V, 5V) with boost/buck converters
- Raspberry Pi Pico/Pico2 connections
- OLED display I2C interface (GP6/GP7)
- MPU9250 9-axis IMU I2C interface (GP20/GP21)
- XBee communication module
- Battery voltage sensing circuit
- LED status indicators
- Limit switches for mission control
- Power management components

#### Breadboard Layout
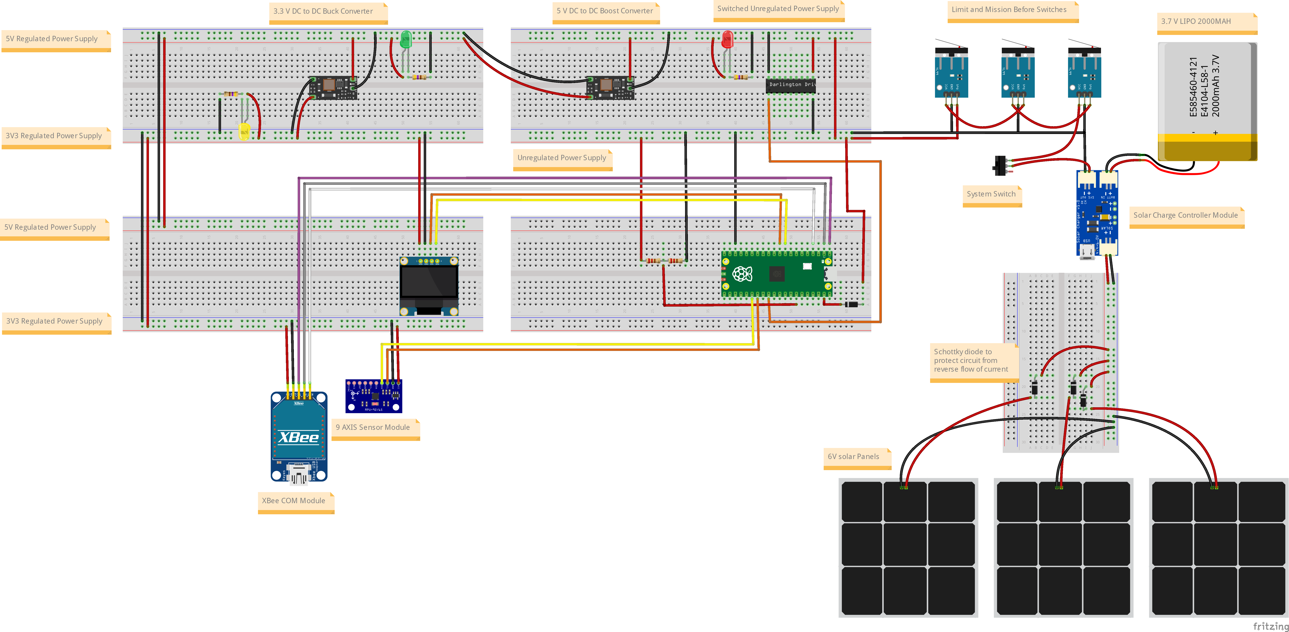
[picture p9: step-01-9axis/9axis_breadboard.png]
VyomSat 9-Axis Breadboard


The breadboard layout provides a practical wiring guide showing:
- Physical component placement
- Wire routing and connections
- Power distribution
- Module interconnections
- MPU9250 sensor positioning

#### Bill of Materials (BOM)
A complete parts list with quantities and specifications is available: **[9axis_bom.html](9axis_bom.html)**

The BOM includes all components from Step 0 plus:
- MPU9250 9-axis IMU sensor module (GY-9250)
- Additional pull-up resistors (4.7kΩ for I2C)
- All resistors, capacitors, ICs, and modules required

> **Fritzing Software**: These diagrams were created using [Fritzing](https://fritzing.org/), an open-source electronics design tool. Download from [fritzing.org/download](https://fritzing.org/download/) to view or modify the designs.

## Architecture

The system builds on Step 0's modular architecture with new IMU capabilities:

### New Module: `vyomsat_9axis_manager.py`
Handles MPU9250 9-axis IMU sensor operations.

**Key Functions:**
- `initialize_9axis_sensor(scl_pin, sda_pin, i2c_frequency)`: Initializes the MPU9250 with I2C configuration
- `read_and_display_9axis_data(uart_handler, oled_manager)`: Reads comprehensive sensor data and displays on USB, UART, and OLED
- `is_9axis_available()`: Checks if sensor is initialized and available
- `get_9axis_status()`: Returns sensor status information

**How it works:**
- Initializes separate I2C bus for MPU9250 (GPIO 20/21)
- Configures both MPU6500 (accelerometer + gyroscope) and AK8963 (magnetometer)
- Reads raw sensor data from all three sensors
- Calculates tilt angles using accelerometer data
- Applies complementary filter for stable attitude estimation
- Calculates magnetic heading from magnetometer data
- Provides formatted output for display and telemetry

**Multi-Screen OLED Display:**
When command 'a' is received, the system cycles through 4 screens (2 seconds each):
1. **Accelerometer Screen**: X, Y, Z axes and total magnitude
2. **Gyroscope Screen**: X, Y, Z axes and total magnitude
3. **Magnetometer Screen**: X, Y, Z axes and total magnitude
4. **Attitude Screen**: Pitch, roll, heading, and temperature

### Updated: `vyomsat.py`
Main integration module extended with 9-axis IMU support.

**Changes from Step 0:**
- Added 9-axis IMU initialization in `main()` function
- Updated command 'a' handler to call `read_and_display_9axis_data()`
- Graceful degradation if IMU not available
- Documentation updated for MPU9250 9-axis sensor

**Operational Flow:**
```
┌─────────────────────────────────────────────┐
│ 1. Initialize Hardware                      │
│    - LED & GPIO pins                        │
│    - XBee hardware reset                    │
│    - Battery ADC sensor                     │
│    - 9-Axis IMU sensor (NEW)                │
│    - OLED display                           │
│    - UART communication                     │
└─────────────────────────────────────────────┘
                    ↓
┌─────────────────────────────────────────────┐
│ 2. Main Loop (every 4 seconds)             │
│    ┌─────────────────────────────────────┐ │
│    │ a. Read battery voltage             │ │
│    │ b. Update OLED with telemetry       │ │
│    │ c. Send telemetry via UART          │ │
│    │ d. Process incoming UART commands   │ │
│    │ e. Print status to USB console      │ │
│    └─────────────────────────────────────┘ │
└─────────────────────────────────────────────┘
```

### Retained Modules from Step 0

**`vyomsat_battery_manager.py`**: Battery voltage sensing via ADC  
**`vyomsat_oled_manager.py`**: SSD1306 OLED display management  
**`vyomsat_xbee_manager.py`**: XBee hardware reset handling

## Telemetry Output

### USB Serial Console - Normal Operation
```
[12345ms] Telemetry Sent | Voltage: 6.90V | Bytes: 65 | Counter: 42
```

### USB Serial Console - 9-Axis Data (Command 'a')
```
======================================================================
MPU9250 9-AXIS IMU ATTITUDE DATA
======================================================================
Timestamp: 12345 ms
Temperature: 25.34 °C

ACCELEROMETER (m/s²):
  X:   0.123  Y:   0.456  Z:   9.789
  Total Magnitude: 9.812 m/s²

GYROSCOPE (°/s):
  X:   0.12  Y:  -0.34  Z:   0.56
  Total Magnitude: 0.67 °/s

MAGNETOMETER (μT):
  X:  23.45  Y: -12.34  Z:  45.67
  Total Magnitude: 52.34 μT

ATTITUDE (FILTERED):
  Pitch:    2.67°
  Roll:    -1.23°
  Heading: 125.4° (Magnetic North)
======================================================================
```

### UART (XBee) - Normal Operation
```
[12345ms] VyomSat EPS | Voltage: 6.90V | Msg: #42
```

### UART (XBee) - 9-Axis Data (Command 'a')
```
======================================================================
MPU9250 9-AXIS IMU COMPREHENSIVE DATA
======================================================================
Timestamp: 12345 ms
Temperature: 25.34 C

ACCELEROMETER (m/s^2):
  X:   0.123  Y:   0.456  Z:   9.789
  Total Magnitude: 9.812 m/s^2

GYROSCOPE (deg/s):
  X:   0.12  Y:  -0.34  Z:   0.56
  Total Magnitude: 0.67 deg/s

MAGNETOMETER (uT):
  X:  23.45  Y: -12.34  Z:  45.67
  Total Magnitude: 52.34 uT

ATTITUDE (FILTERED):
  Pitch:    2.67 deg
  Roll:    -1.23 deg
  Heading: 125.4 deg (Magnetic North)
======================================================================
```

### OLED Display - Normal Operation
```
VyomSat EPS
Time: 14:23:45
Batt: 6.90V
Msg: 42
```

### OLED Display - 9-Axis Data (Command 'a' - 4 Screens)

**Screen 1: Accelerometer (2 seconds)**
```
ACCELEROMETER  14:23:45
X:  0.12m/s2
Y:  0.46m/s2
Z:  9.79m/s2
Mag:  9.81m/s2
```

**Screen 2: Gyroscope (2 seconds)**
```
GYROSCOPE      14:23:45
X:    0.1deg/s
Y:   -0.3deg/s
Z:    0.6deg/s
Mag:   0.7deg/s
```

**Screen 3: Magnetometer (2 seconds)**
```
MAGNETOMETER   14:23:45
X:   23.5uT
Y:  -12.3uT
Z:   45.7uT
Mag:  52.3uT
```

**Screen 4: Attitude & Temperature (2 seconds)**
```
ATTITUDE       14:23:45
Pitch:   2.7deg
Roll:   -1.2deg
Hdg:   125.4deg
Temp:  25.3C
```

## Supported UART Commands

Send single character commands to control the system:

| Command | Function | Response | Status |
|---|---|---|---|
| `a` | **9-axis IMU attitude data** | Comprehensive sensor data | **NEW** ✨ |
| `v` | Request voltage reading | Detailed voltage data | Active |
| `b` | System reset | ACK (placeholder) | Reserved |
| `c` | Camera capture | ACK (placeholder) | Reserved |
| `s` | SD card logging | ACK (placeholder) | Reserved |
| `g` | GPS data capture | ACK (placeholder) | Reserved |

### Command 'a' - 9-Axis Attitude Data (NEW)

**Behavior:**
1. Reads comprehensive data from MPU9250
2. Displays detailed output on USB serial console
3. Sends formatted data via UART
4. Cycles through 4 OLED screens (8 seconds total)
5. Returns to normal telemetry display

**Example:**
```
Send: a

Receive (UART): ACK: MPU9250 capture initiated
                [comprehensive 9-axis data follows]

Display (OLED): [4 screens cycle automatically]
```

### Command 'v' - Voltage Reading

**Example:**
```
Send: v

Receive: ACK: Battery voltage reading initiated
         [timestamp] BATTERY VOLTAGE | Batt: 6.900V | ADC: 3.450V | Raw: 32768
```

## Usage

### 1. Setup Hardware
Connect all components according to the wiring table above. Pay special attention to:
- 4.7kΩ pull-up resistors on MPU9250 I2C lines (SCL and SDA)
- Separate I2C buses for OLED (GP6/7) and IMU (GP20/21)
- Common ground connections for all modules

### 2. Get Required Libraries

The manager modules depend on sensor and breakout board libraries from the [OjasJha/micropython-lib](https://github.com/OjasJha/micropython-lib.git) repository.

Clone or download the repository:
```bash
git clone https://github.com/OjasJha/micropython-lib.git
```

**Required libraries for Step 1:**

*From Step 0:*
- `com/uart/uart_handler.py` - UART communication handler
- `io/oled-ssd1306/ssd1306_handler.py` - SSD1306 OLED display driver

*NEW for Step 1:*
- `sensors/mpu9250/mpu9250_handler.py` - MPU9250 9-axis IMU handler
- `sensors/mpu9250/mpu6500_handler.py` - MPU6500 6-axis IMU handler (accelerometer + gyroscope)
- `sensors/mpu9250/ak8963_handler.py` - AK8963 3-axis magnetometer handler
- `sensors/mpu9250/mpu9250.py` - Low-level MPU9250 driver
- `sensors/mpu9250/mpu6500.py` - Low-level MPU6500 driver
- `sensors/mpu9250/ak8963.py` - Low-level AK8963 driver

> **Important**: Copy these library files directly to the same folder as the VyomSat modules (flat structure). Do NOT maintain the directory structure from the repository.

### 3. Upload Code

Copy all Python files to your Raspberry Pi Pico in the **same folder**:

**VyomSat Step 1 Modules:**
- `vyomsat.py`
- `vyomsat_battery_manager.py`
- `vyomsat_oled_manager.py`
- `vyomsat_xbee_manager.py`
- `vyomsat_9axis_manager.py` ← **NEW**

**Libraries from micropython-lib repository:**
- `uart_handler.py` (from `com/uart/`)
- `ssd1306_handler.py` (from `io/oled-ssd1306/`)
- `mpu9250_handler.py` (from `sensors/mpu9250/`) ← **NEW**
- `mpu6500_handler.py` (from `sensors/mpu9250/`) ← **NEW**
- `ak8963_handler.py` (from `sensors/mpu9250/`) ← **NEW**
- `mpu9250.py` (from `sensors/mpu9250/`) ← **NEW**
- `mpu6500.py` (from `sensors/mpu9250/`) ← **NEW**
- `ak8963.py` (from `sensors/mpu9250/`) ← **NEW**

All files should be in the root directory of your Pico, or in the same folder.

### 4. Run
```python
# On Pico - execute main script
python vyomsat.py
```

Or set it as `main.py` to run automatically on boot.

### 5. Monitor & Test

**Startup:**
1. Watch USB console for initialization messages
2. Verify 9-axis IMU initialization: `[OK]9-axis IMU sensor initialized successfully!`
3. Check OLED display shows normal telemetry

**Test Command 'a':**
1. Send 'a' via UART (XBee)
2. Observe USB console for detailed 9-axis data
3. Watch OLED cycle through 4 screens (8 seconds)
4. Receive comprehensive data via UART
5. Move/rotate sensor and observe changing values

**Normal Operation:**
- **USB Console**: Monitor debug output (115200 baud)
- **OLED**: View real-time telemetry
- **XBee**: Receive telemetry stream and send commands

## Configuration

Key constants in `vyomsat.py`:

```python
# OLED Display
OLED_SCL_PIN = 7              # I2C clock pin
OLED_SDA_PIN = 6              # I2C data pin

# Battery Monitoring
BATTERY_ADC_CHANNEL = 2                    # ADC2 (GP28)
BATTERY_VOLTAGE_DIVIDER_FACTOR = 0.5       # 2:1 voltage divider

# UART Communication
UART_BAUDRATE = 9600          # Standard XBee baudrate
UART_TX_PIN = 0               # GP0
UART_RX_PIN = 1               # GP1

# XBee Reset
XBEE_RESET_PIN = 2            # GP2
XBEE_INIT_DELAY_SECONDS = 5   # Boot delay

# 9-Axis IMU Sensor (NEW)
NINE_AXIS_SCL_PIN = 21        # GPIO 21 for I2C Serial Clock
NINE_AXIS_SDA_PIN = 20        # GPIO 20 for I2C Serial Data
NINE_AXIS_I2C_FREQ = 400000   # I2C bus frequency (400kHz)

# Telemetry Rate
MAIN_LOOP_DELAY_SECONDS = 4   # Update interval
```

## Understanding the 9-Axis Data

### When Sensor is Stationary (Level Surface)

| Sensor | Expected Reading | Meaning |
|---|---|---|
| Accelerometer | ~9.81 m/s² (Z-axis) | Measures Earth's gravity |
| | ~0 m/s² (X, Y axes) | No horizontal acceleration |
| Gyroscope | ~0 °/s (all axes) | No rotation (minor drift is normal) |
| Magnetometer | Varies by location | Earth's magnetic field (25-65 μT) |
| Pitch | ~0° | Level (front-back) |
| Roll | ~0° | Level (left-right) |
| Heading | Depends on orientation | Compass direction |

### When Sensor is Moving/Rotating

| Motion | Sensor Response |
|---|---|
| Tilting forward | Accelerometer: X increases, Pitch increases |
| Tilting left | Accelerometer: Y changes, Roll changes |
| Rotating horizontally | Gyroscope: Z-axis shows rotation rate, Heading changes |
| Linear motion | Accelerometer shows combined gravity + motion |
| Fast rotation | Gyroscope values increase |

### Coordinate System

```
      Z (Up)
      |
      |
      +---- X (Forward)
     /
    /
   Y (Right)
```

## Troubleshooting

| Issue | Solution |
|---|---|
| **9-axis IMU not initializing** | Check wiring (SCL→GP21, SDA→GP20, VCC→3.3V, GND→GND) |
| | Verify 4.7kΩ pull-up resistors on both SCL and SDA |
| | Check I2C address: MPU6500 (0x68), AK8963 (0x0C) |
| | Ensure bypass mode enabled for magnetometer |
| **Incorrect accelerometer readings** | Should read ~9.81 m/s² total when stationary |
| | Calibrate if consistently offset |
| **Gyroscope drifting** | Normal to have small drift (~0.5 °/s) |
| | Excessive drift may indicate temperature effects |
| **Magnetometer readings unstable** | Keep away from magnetic interference (motors, speakers) |
| | Hard iron calibration may be needed |
| | Ensure sensor is away from metal objects |
| **Heading incorrect** | Magnetometer needs calibration for local environment |
| | Sensor orientation matters for heading calculation |
| | Declination angle correction may be needed |
| **OLED screens not cycling** | Verify OLED manager is passed to function |
| | Check USB console for error messages |
| **No OLED display** | Check I2C wiring (SCL→GP7, SDA→GP6) and power |
| **OLED garbled text** | Try I2C address 0x3D instead of 0x3C |
| **No UART communication** | Verify TX/RX connections and common ground |
| **Incorrect voltage** | Check voltage divider circuit and calibration |

## Technical Details

### MPU9250 Sensor Architecture

The MPU9250 contains two sensors in one package:

**MPU6500 (6-axis IMU):**
- I2C Address: 0x68
- 3-axis accelerometer: ±2g, ±4g, ±8g, ±16g
- 3-axis gyroscope: ±250, ±500, ±1000, ±2000 °/s
- Temperature sensor: -40°C to +85°C
- 16-bit ADCs for high precision

**AK8963 (3-axis Magnetometer):**
- I2C Address: 0x0C (accessed through MPU6500 bypass)
- Measurement range: ±4800 μT
- 14-bit or 16-bit output
- Compass accuracy: better than 0.6° RMS

### Sensor Fusion Algorithm

The system uses a complementary filter to combine accelerometer and gyroscope data:

```
Filtered_Angle = α × (Gyro_Angle) + (1-α) × (Accel_Angle)
```

- **α (alpha)**: Typically 0.96-0.98
- **Gyro_Angle**: Short-term accuracy, drifts over time
- **Accel_Angle**: Long-term accuracy, noisy short-term
- **Result**: Stable, responsive angle estimation

### ADC Resolution
- **Hardware**: 12-bit ADC (0-4095)
- **MicroPython**: 16-bit reading (0-65535)
- **Reference**: 3.3V
- **Conversion Factor**: 3.3V / 65535 = 0.0000503540 V/count

### I2C Communication

| Bus | Pins | Frequency | Address | Purpose |
|-----|---|---|---|---|
| I2C0 | GP6/GP7 | 400 kHz | 0x3C | OLED Display |
| I2C1 | GP20/GP21 | 400 kHz | 0x68, 0x0C | MPU9250 IMU |

### UART Communication
- **Baud Rate**: 9600 bps
- **Data Bits**: 8
- **Parity**: None
- **Stop Bits**: 1
- **Flow Control**: None

## Changes from Step 0

### Hardware Additions
- ✅ MPU9250 9-axis IMU sensor module
- ✅ 4.7kΩ pull-up resistors for I2C (SCL and SDA)
- ✅ Additional I2C bus (GP20/GP21)

### Software Additions
- ✅ `vyomsat_9axis_manager.py` - New module for IMU management
- ✅ MPU9250 handler libraries (4 files)
- ✅ Command 'a' implementation for attitude data
- ✅ Multi-screen OLED display cycling
- ✅ Sensor fusion for tilt angle calculation
- ✅ Heading calculation from magnetometer

### Functional Improvements
- ✅ Complete 9-axis motion sensing capability
- ✅ Real-time attitude data (pitch, roll, heading)
- ✅ Comprehensive telemetry output (USB, UART, OLED)
- ✅ Graceful degradation if IMU not available
- ✅ Enhanced error handling and status reporting

## Testing Procedure

### 1. Hardware Verification
- [ ] All connections secure and correct
- [ ] 4.7kΩ pull-up resistors installed on IMU I2C lines
- [ ] Power supply stable (3.3V to all modules)
- [ ] Common ground connected to all modules

### 2. Software Verification
- [ ] All required libraries uploaded to Pico
- [ ] Main script runs without errors
- [ ] USB console shows successful initialization

### 3. Sensor Testing
- [ ] Battery voltage displays correctly
- [ ] OLED shows normal telemetry
- [ ] UART telemetry transmits every 4 seconds
- [ ] IMU initialization message: `[OK]9-axis IMU sensor initialized successfully!`

### 4. Command 'a' Testing
- [ ] Send 'a' via UART
- [ ] USB console shows comprehensive 9-axis data
- [ ] UART receives complete attitude data
- [ ] OLED cycles through 4 screens (8 seconds total)
- [ ] System returns to normal telemetry

### 5. Motion Testing
- [ ] Place sensor on level surface: pitch and roll near 0°
- [ ] Tilt forward: pitch increases
- [ ] Tilt left: roll changes
- [ ] Rotate horizontally: heading changes
- [ ] Move quickly: gyroscope shows rotation rates
- [ ] Total acceleration near 9.81 m/s² when stationary

## License

MIT License - Copyright (c) 2025 Ojas Jha

See individual Python files for full license text.

## Author

**Ojas Jha**  
VyomSat CubeSat Education Kit  
Date: October 25, 2025

## Acknowledgments

- Step 0 (EPS + COM) provides the foundation for this implementation
- MPU9250 sensor drivers based on community MicroPython libraries
- Fritzing diagrams created with Fritzing open-source software

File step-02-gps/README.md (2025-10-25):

# VyomSat Step 2: EPS + COM + 9-Axis IMU + GPS Integration

**VyomSat - Essence of Space. Built by You.**

This step builds upon Step 1 (EPS + COM + 9-Axis IMU) by adding GPS positioning capabilities using the NEO-6M GPS module. The system now provides complete location tracking with latitude, longitude, altitude, and satellite information for CubeSat applications.

## Overview

Step 2 extends the 9-axis attitude sensing system with GPS positioning capabilities. The system continuously measures battery voltage, communicates via UART, provides comprehensive attitude data through the MPU9250 IMU, and now tracks precise geographic location using GPS satellites.

**New in Step 2:**
- 🛰️ **NEO-6M GPS Module** - Complete position tracking with satellite navigation
- 📍 **Location Data** - Latitude, longitude, altitude, and satellite count
- 🕐 **GPS Time & Date** - UTC time with local timezone conversion
- 🎯 **Command 'g'** - Real-time GPS data capture and telemetry transmission
- 🌐 **Speed & Heading** - Course over ground and compass direction from GPS
- 📊 **Enhanced Telemetry** - GPS coordinates integrated into regular data stream

**Retained from Step 1:**
- 🧭 MPU9250 9-Axis IMU (accelerometer, gyroscope, magnetometer)
- 📊 Attitude Data (pitch, roll, heading)
- 🎯 Command 'a' for 9-axis data capture
- 📈 Sensor Fusion for tilt angle estimation

**Retained from Step 0:**
- 📊 Battery Voltage Monitoring
- 📺 OLED Display (128x64 SSD1306)
- 📡 UART Communication (XBee)
- 🎛️ Command Interface
- ⚡ Hardware Reset Management

## Features

### GPS Positioning Capabilities

The NEO-6M GPS module provides complete satellite navigation:

- **Position Data**: Geographic coordinates
  - Latitude: Degrees, minutes, seconds + decimal degrees
  - Longitude: Degrees, minutes, seconds + decimal degrees
  - Altitude: Meters above mean sea level
  - Geoid separation: Height of geoid above WGS84 ellipsoid

- **Time & Date**: UTC time from GPS satellites
  - GPS Time: Hours, minutes, seconds (UTC)
  - Local Time: Configurable timezone offset (default: UTC+4 for Dubai)
  - Date: Day, month, year

- **Motion Data**: Speed and direction
  - Speed: km/h, mph, knots
  - Course over ground: 0-360 degrees
  - Compass direction: N, NE, E, SE, S, SW, W, NW

- **Satellite Information**: Fix quality metrics
  - Satellites in view: Total visible satellites
  - Satellites in use: Satellites used for position fix
  - Satellite IDs: List of PRN numbers in use

- **Fix Quality Metrics**: Accuracy indicators
  - HDOP: Horizontal Dilution of Precision
  - VDOP: Vertical Dilution of Precision
  - PDOP: Position Dilution of Precision
  - Fix quality: 0=Invalid, 1=GPS fix, 2=DGPS fix
  - Fix type: 1=No fix, 2=2D fix, 3=3D fix

### GPS Integration Features

- **Continuous GPS Reading**: Non-blocking UART read from NEO-6M
- **NMEA Sentence Parsing**: GGA, RMC, GSA, GSV sentence support
- **Basic GPS Data**: Integrated into regular telemetry (lat/lon)
- **Comprehensive GPS Display**: Detailed diagnostics via command 'g'
- **Multi-Screen OLED**: 3 GPS screens showing position, time/motion, quality
- **Graceful Degradation**: System works even if GPS not available or no fix

## Hardware Requirements

### Components

- Raspberry Pi Pico 2 or Pico W
- SSD1306 OLED Display (128x64 pixels, I2C)
- MPU9250 9-Axis IMU Sensor Module (I2C)
- **NEO-6M GPS Module (UART)** ← **NEW**
- XBee module (or compatible UART device)
- Battery voltage divider circuit
- 4.7kΩ pull-up resistors for I2C lines (2x for IMU)

### Wiring Connections

| Component | Pico Pin | Description |
|---|---|---|
| **OLED Display** | | |
| SCL | GP7 | I2C Serial Clock |
| SDA | GP6 | I2C Serial Data |
| VCC | 3.3V | Power |
| GND | GND | Ground |
| **MPU9250 9-Axis IMU** | | |
| SCL | GP21 | I2C Serial Clock |
| SDA | GP20 | I2C Serial Data |
| VCC | 3.3V | Power |
| GND | GND | Ground |
| **NEO-6M GPS Module** | | **NEW** |
| TX (GPS → Pico) | GP5 | UART1 Receive |
| RX (Pico → GPS) | GP4 | UART1 Transmit |
| VCC | 3.3V | Power |
| GND | GND | Ground |
| **XBee Module** | | |
| TX (Pico → XBee) | GP0 | UART0 Transmit |
| RX (XBee → Pico) | GP1 | UART0 Receive |
| RST | GP2 | Hardware Reset (optional) |
| GND | GND | Common Ground |
| **Battery Sensing** | | |
| ADC Input | GP28 | Battery voltage via divider |

> **Important Notes**: 
> - The NEO-6M GPS module requires a clear view of the sky for satellite acquisition
> - GPS cold start can take 30+ seconds, warm start typically 1-5 seconds
> - UART1 (GP4/GP5) is used for GPS communication at 9600 baud
> - UART0 (GP0/GP1) remains for XBee communication
> - The MPU9250 requires 4.7kΩ pull-up resistors on both SCL and SDA lines
> - Battery voltage must be reduced to 0-3.3V range using a voltage divider circuit

### Circuit Diagrams

Visual references for hardware setup are provided using Fritzing diagrams:

#### Schematic Diagram
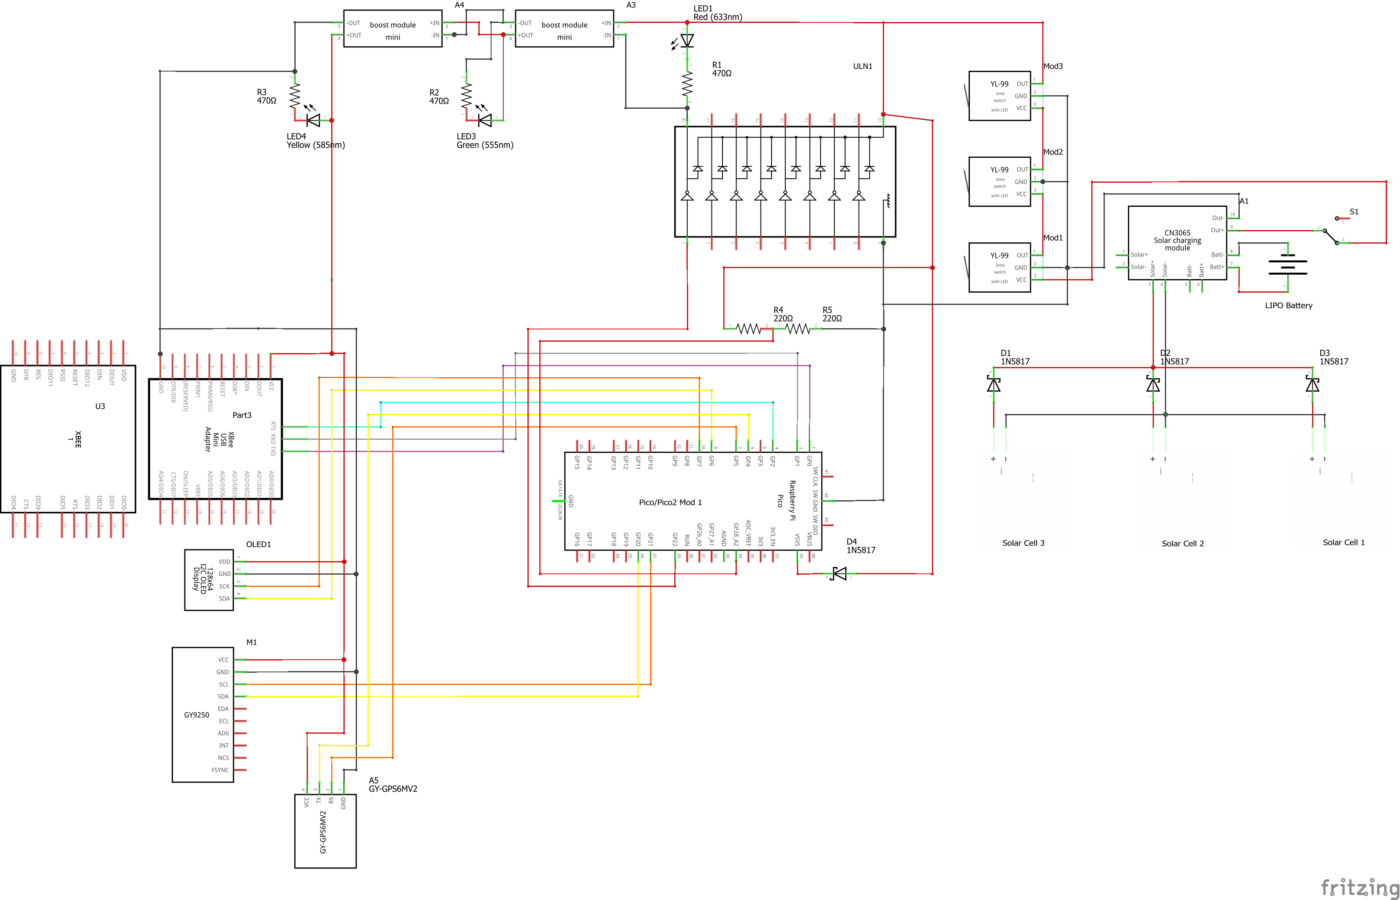
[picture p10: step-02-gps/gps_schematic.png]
VyomSat GPS Schematic


The schematic shows the complete electrical connections including:
- Solar panel array with charge controller (CN3065)
- Multiple power rails (3.3V, 5V) with boost/buck converters
- Raspberry Pi Pico/Pico2 connections
- OLED display I2C interface (GP6/GP7)
- MPU9250 9-axis IMU I2C interface (GP20/GP21)
- NEO-6M GPS module UART1 interface (GP4/GP5)
- XBee communication module on UART0 (GP0/GP1)
- Battery voltage sensing circuit
- LED status indicators
- Limit switches for mission control
- Power management components

#### Breadboard Layout
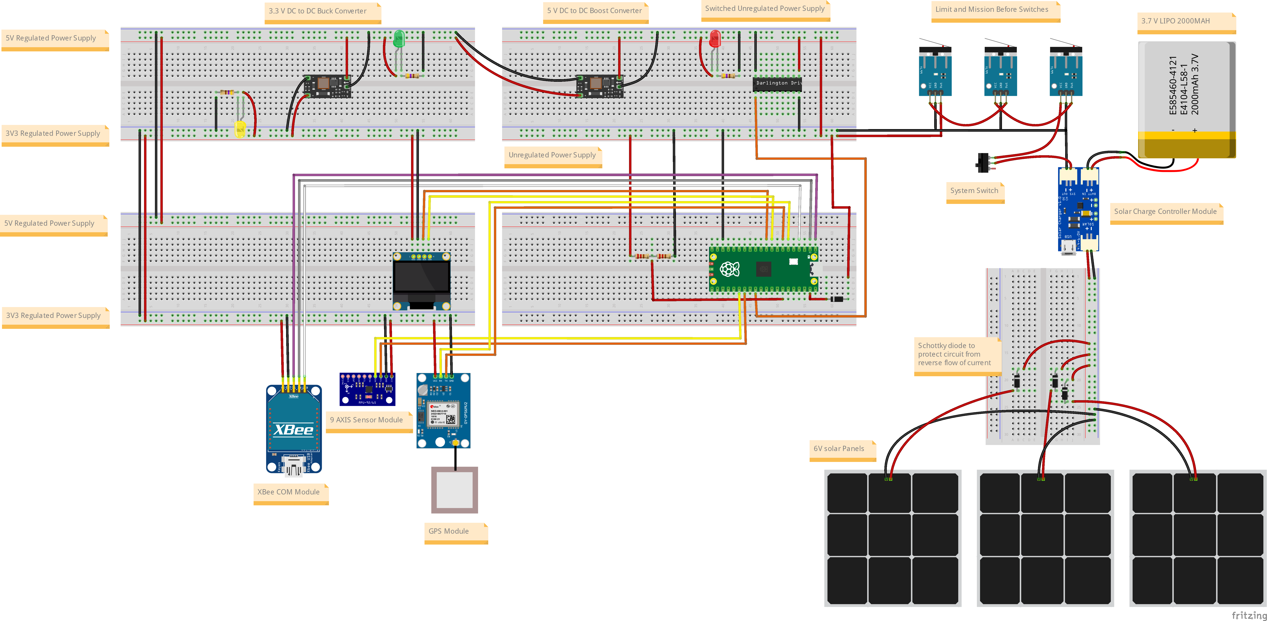
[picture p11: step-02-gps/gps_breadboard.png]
VyomSat GPS Breadboard


The breadboard layout provides a practical wiring guide showing:
- Physical component placement
- Wire routing and connections
- Power distribution
- Module interconnections
- GPS module positioning with antenna

#### Bill of Materials (BOM)
A complete parts list with quantities and specifications is available: **[gps_bom.html](gps_bom.html)**

The BOM includes all components from Steps 0 and 1 plus:
- NEO-6M GPS sensor module (GY-GPS6MV2)
- GPS ceramic antenna (usually integrated with module)
- All resistors, capacitors, ICs, and modules required

> **Fritzing Software**: These diagrams were created using [Fritzing](https://fritzing.org/), an open-source electronics design tool. Download from [fritzing.org/download](https://fritzing.org/download/) to view or modify the designs.

## Architecture

The system builds on Step 1's modular architecture with new GPS capabilities:

### New Module: `vyomsat_gps_manager.py`
Handles NEO-6M GPS sensor operations and NMEA sentence parsing.

**Key Functions:**
- `initialize_gps_sensor(uart_id, tx_pin, rx_pin, baudrate, timezone_offset_hours)`: Initializes GPS with UART1 configuration
- `read_gps_data()`: Non-blocking GPS data read from UART (call in main loop)
- `get_basic_gps_data()`: Returns lat/lon for regular telemetry display
- `read_and_display_full_gps_data(uart_handler, oled_manager)`: Comprehensive GPS diagnostics
- `is_gps_available()`: Checks if GPS has valid fix
- `update_oled_with_gps_and_hk(oled_manager, battery_voltage, message_counter)`: Updates OLED with GPS + housekeeping data

**How it works:**
- Initializes UART1 for GPS communication (9600 baud on GPIO 4/5)
- Creates NEO6MV2Handler instance for NMEA sentence parsing
- Reads GPS data non-blockingly in main loop
- Parses NMEA sentences: GGA (position), RMC (time/motion), GSA (satellites), GSV (satellite view)
- Provides basic GPS data (lat/lon) for regular telemetry
- Provides comprehensive GPS diagnostics on command 'g'
- Formats GPS data for USB console, UART transmission, and OLED display

**Multi-Screen OLED Display:**
When command 'g' is received, the system cycles through 3 screens (2 seconds each):
1. **Position Screen**: Latitude, longitude, altitude, satellite count
2. **Time/Motion Screen**: Local time, date, speed, course
3. **Quality Screen**: Fix quality, fix type, HDOP, PDOP

**Regular Telemetry Display:**
In normal operation, OLED shows:
- Header: "VyomSat EPS+GPS"
- Time: System uptime in HH:MM:SS
- Battery voltage
- GPS latitude (if fix available)
- GPS longitude (if fix available)
- GPS acquisition status (if no fix)

### Updated: `vyomsat.py`
Main integration module extended with GPS support.

**Changes from Step 1:**
- Added GPS sensor initialization in `main()` function
- Added `read_gps_data()` call in main loop (non-blocking GPS read)
- Updated telemetry messages to include GPS lat/lon when fix available
- Updated command 'g' handler to call `read_and_display_full_gps_data()`
- Added 10ms delay in main loop to prevent I2C bus contention
- Enhanced OLED display to show GPS data
- Graceful degradation if GPS not available or no fix
- Documentation updated for GPS sensor integration

**Operational Flow:**
```
┌─────────────────────────────────────────────┐
│ 1. Initialize Hardware                      │
│    - LED & GPIO pins                        │
│    - XBee hardware reset                    │
│    - Battery ADC sensor                     │
│    - 9-Axis IMU sensor                      │
│    - GPS sensor (NEW)                       │
│    - OLED display                           │
│    - UART communication                     │
└─────────────────────────────────────────────┘
                    ↓
┌─────────────────────────────────────────────┐
│ 2. Main Loop (every 4 seconds)             │
│    ┌─────────────────────────────────────┐ │
│    │ a. Read GPS data (non-blocking)     │ │ ← NEW
│    │ b. Read battery voltage             │ │
│    │ c. Get basic GPS data               │ │ ← NEW
│    │ d. Update OLED with GPS + HK        │ │ ← NEW
│    │ e. Send telemetry via UART (w/ GPS) │ │ ← NEW
│    │ f. Process incoming UART commands   │ │
│    │ g. Print status to USB console      │ │
│    └─────────────────────────────────────┘ │
└─────────────────────────────────────────────┘
```

### Retained Modules from Previous Steps

**`vyomsat_9axis_manager.py`**: MPU9250 9-axis IMU sensor management (Step 1)  
**`vyomsat_battery_manager.py`**: Battery voltage sensing via ADC (Step 0)  
**`vyomsat_oled_manager.py`**: SSD1306 OLED display management (Step 0)  
**`vyomsat_xbee_manager.py`**: XBee hardware reset handling (Step 0)

## Telemetry Output

### USB Serial Console - Normal Operation (with GPS fix)
```
[12345ms] Telemetry Sent | V: 6.90V | GPS: 25.2521, 55.3095 | Alt: 15.2m | Sats: 8 | Counter: 42
```

### USB Serial Console - Normal Operation (no GPS fix)
```
[12345ms] Telemetry Sent | V: 6.90V | GPS: Acquiring... | Counter: 42
```

### USB Serial Console - GPS Data (Command 'g')
```
======================================================================
COMPREHENSIVE GPS DIAGNOSTIC DATA
======================================================================

POSITION DATA:
----------------------------------------
Latitude (decimal):      25.2521° N
Longitude (decimal):     55.3095° E
Altitude:                15.2 m
Geoid Height:            -20.4 m

TIME & DATE DATA:
----------------------------------------
GPS Time (local):        16:45:23.50
Date:                    25/10/2025
Timezone Offset (h):     4

MOTION DATA:
----------------------------------------
Course/Heading:          125.4°
Compass Direction:       SE
Speed (km/h):            0.0 km/h
Speed (mph):             0.0 mph
Speed (knots):           0.0 knots

SATELLITE DATA:
----------------------------------------
Satellites in View:      12
Satellites in Use:       8
Satellites Used List:    [2, 5, 12, 15, 17, 25, 29, 30]

FIX QUALITY DATA:
----------------------------------------
Fix Status (GGA):        1
Fix Type  (GSA):         3
Valid Fix:               True
Time Since Fix:          234 ms

DILUTION OF PRECISION:
----------------------------------------
HDOP:                    1.2
VDOP:                    1.8
PDOP:                    2.1

======================================================================
```

### UART (XBee) - Normal Operation (with GPS fix)
```
[12345ms] VyomSat EPS | V: 6.90V | Lat: 25.2521 | Lon: 55.3095 | Alt: 15.2m | Sats: 8 | Msg: #42
```

### UART (XBee) - GPS Data (Command 'g')
```
GPS DATA:
Lat: 25.2521° N | Lon: 55.3095° E
Alt: 15.2m | Sats: 8
Time: 16:45:23.50 | Date: 25/10/2025
Speed: 0.0 km/h | Course: 125.4deg
HDOP: 1.2 | VDOP: 1.8 | PDOP: 2.1
```

### OLED Display - Normal Operation (with GPS fix)
```
VyomSat EPS+GPS
00:03:25
V: 6.90V
Lat:25.2521° N
Lon:55.3095° E
```

### OLED Display - Normal Operation (no GPS fix)
```
VyomSat EPS+GPS
00:03:25
V: 6.90V
GPS: Acquiring
Sats:3
```

### OLED Display - GPS Data (Command 'g' - 3 Screens)

**Screen 1: Position (2 seconds)**
```
GPS Position
Lat:25.2521° N
Lon:55.3095° E
Alt:15.2m
Sats:8
```

**Screen 2: Time/Motion (2 seconds)**
```
GPS Time/Motion
Time:16:45:23
Date:25/10/2025
Spd:0.0km/h
Crs:125deg
```

**Screen 3: Fix Quality (2 seconds)**
```
GPS Quality
Fix:1
Type:3
HDOP:1.20
PDOP:2.10
```

## Supported UART Commands

Send single character commands to control the system:

| Command | Function | Response | Status |
|---|---|---|---|
| `g` | **GPS position data** | Comprehensive GPS diagnostics | **NEW** ✨ |
| `a` | 9-axis IMU attitude data | Comprehensive sensor data | Active |
| `v` | Request voltage reading | Detailed voltage data | Active |
| `b` | System reset | ACK (placeholder) | Reserved |
| `c` | Camera capture | ACK (placeholder) | Reserved |
| `s` | SD card logging | ACK (placeholder) | Reserved |

### Command 'g' - GPS Position Data (NEW)

**Behavior:**
1. Reads comprehensive GPS data from NEO-6M
2. Displays detailed output on USB serial console
3. Sends formatted GPS data via UART
4. Cycles through 3 OLED screens (6 seconds total)
5. Returns to normal telemetry display

**Example:**
```
Send: g

Receive (UART): ACK: GPS capture initiated
                [comprehensive GPS data follows]

Display (OLED): [3 screens cycle automatically]
```

### Command 'a' - 9-Axis Attitude Data

**Example:**
```
Send: a

Receive: ACK: MPU9250 capture initiated
         [comprehensive 9-axis IMU data follows]
```

### Command 'v' - Voltage Reading

**Example:**
```
Send: v

Receive: ACK: Battery voltage reading initiated
         [timestamp] BATTERY VOLTAGE | Batt: 6.900V | ADC: 3.450V | Raw: 32768
```

## Usage

### 1. Setup Hardware
Connect all components according to the wiring table above. Pay special attention to:
- NEO-6M GPS module on UART1 (GP4 TX, GP5 RX)
- GPS antenna with clear view of sky
- 4.7kΩ pull-up resistors on MPU9250 I2C lines (SCL and SDA)
- Separate I2C buses for OLED (GP6/7) and IMU (GP20/21)
- Common ground connections for all modules

### 2. Get Required Libraries

The manager modules depend on sensor and breakout board libraries from the [OjasJha/micropython-lib](https://github.com/OjasJha/micropython-lib.git) repository.

Clone or download the repository:
```bash
git clone https://github.com/OjasJha/micropython-lib.git
```

**Required libraries for Step 2:**

*From Step 0:*
- `com/uart/uart_handler.py` - UART communication handler

*From Step 1:*
- `io/oled-ssd1306/ssd1306_handler.py` - SSD1306 OLED display driver
- `sensors/mpu9250/mpu9250_handler.py` - MPU9250 9-axis IMU handler
- `sensors/mpu9250/mpu6500_handler.py` - MPU6500 6-axis IMU handler
- `sensors/mpu9250/ak8963_handler.py` - AK8963 3-axis magnetometer handler
- `sensors/mpu9250/mpu9250.py` - Low-level MPU9250 driver
- `sensors/mpu9250/mpu6500.py` - Low-level MPU6500 driver
- `sensors/mpu9250/ak8963.py` - Low-level AK8963 driver

*NEW for Step 2:*
- `sensors/gps/neo6mv2_handler.py` - NEO-6M GPS handler with NMEA parsing

> **Important**: Copy these library files directly to the same folder as the VyomSat modules (flat structure). Do NOT maintain the directory structure from the repository.

### 3. Upload Code

Copy all Python files to your Raspberry Pi Pico in the **same folder**:

**VyomSat Step 2 Modules:**
- `vyomsat.py` (updated)
- `vyomsat_battery_manager.py`
- `vyomsat_oled_manager.py`
- `vyomsat_xbee_manager.py`
- `vyomsat_9axis_manager.py`
- `vyomsat_gps_manager.py` ← **NEW**

**Libraries from micropython-lib repository:**
- `uart_handler.py` (from `com/uart/`)
- `ssd1306_handler.py` (from `io/oled-ssd1306/`)
- `mpu9250_handler.py` (from `sensors/mpu9250/`)
- `mpu6500_handler.py` (from `sensors/mpu9250/`)
- `ak8963_handler.py` (from `sensors/mpu9250/`)
- `mpu9250.py` (from `sensors/mpu9250/`)
- `mpu6500.py` (from `sensors/mpu9250/`)
- `ak8963.py` (from `sensors/mpu9250/`)
- `neo6mv2_handler.py` (from `sensors/gps/`) ← **NEW**

All files should be in the root directory of your Pico, or in the same folder.

### 4. Run
```python
# On Pico - execute main script
python vyomsat.py
```

Or set it as `main.py` to run automatically on boot.

### 5. Monitor & Test

**Startup:**
1. Watch USB console for initialization messages
2. Verify GPS initialization: `[OK] GPS sensor initialized on UART1`
3. Verify 9-axis IMU initialization: `[OK] 9-axis IMU sensor initialized successfully!`
4. Check OLED display shows normal telemetry with GPS status

**GPS Acquisition (first time or cold start):**
1. Ensure GPS antenna has clear view of sky
2. Wait 30-60 seconds for initial satellite acquisition
3. Monitor satellite count increasing
4. Watch for GPS fix confirmation in telemetry

**Test Command 'g':**
1. Wait for GPS to acquire fix (Sats > 4)
2. Send 'g' via UART (XBee)
3. Observe USB console for detailed GPS data
4. Watch OLED cycle through 3 screens (6 seconds)
5. Receive comprehensive GPS data via UART
6. Move location and observe changing coordinates

**Normal Operation:**
- **USB Console**: Monitor debug output with GPS coordinates (115200 baud)
- **OLED**: View real-time telemetry with GPS position
- **XBee**: Receive telemetry stream with GPS data and send commands

## Configuration

Key constants in `vyomsat.py`:

```python
# OLED Display
OLED_SCL_PIN = 7              # I2C clock pin
OLED_SDA_PIN = 6              # I2C data pin

# Battery Monitoring
BATTERY_ADC_CHANNEL = 2                    # ADC2 (GP28)
BATTERY_VOLTAGE_DIVIDER_FACTOR = 0.5       # 2:1 voltage divider

# UART Communication (XBee)
UART_BAUDRATE = 9600          # Standard XBee baudrate
UART_TX_PIN = 0               # GP0
UART_RX_PIN = 1               # GP1

# XBee Reset
XBEE_RESET_PIN = 2            # GP2
XBEE_INIT_DELAY_SECONDS = 5   # Boot delay

# 9-Axis IMU Sensor
NINE_AXIS_SCL_PIN = 21        # GPIO 21 for I2C Serial Clock
NINE_AXIS_SDA_PIN = 20        # GPIO 20 for I2C Serial Data
NINE_AXIS_I2C_FREQ = 400000   # I2C bus frequency (400kHz)

# GPS Sensor (NEW)
GPS_UART_ID = 1               # UART1 interface
GPS_TX_PIN = 4                # GPIO 4 for UART1 TX
GPS_RX_PIN = 5                # GPIO 5 for UART1 RX
GPS_BAUDRATE = 9600           # NEO-6M default baudrate
GPS_TIMEZONE_OFFSET = 4       # Dubai/UAE timezone (UTC+4)

# Telemetry Rate
MAIN_LOOP_DELAY_SECONDS = 4   # Update interval
```

## Understanding GPS Data

### NMEA Sentences

The NEO-6M GPS module outputs standard NMEA 0183 sentences:

| Sentence | Purpose | Data Provided |
|---|---|---|
| **GPGGA** | Global Positioning System Fix Data | Position, altitude, fix quality, satellites |
| **GPRMC** | Recommended Minimum Navigation Information | Position, speed, course, date/time |
| **GPGSA** | GPS DOP and Active Satellites | Fix type, satellite IDs, HDOP/VDOP/PDOP |
| **GPGSV** | GPS Satellites in View | Satellite count, elevation, azimuth, SNR |

### GPS Fix Types

| Fix Type | Meaning | GPS Usability |
|---|---|---|
| **0 (No Fix)** | GPS not locked to satellites | Position invalid |
| **1 (GPS Fix)** | Standard GPS positioning | Position valid (±10m accuracy) |
| **2 (DGPS Fix)** | Differential GPS (enhanced) | Position valid (±1m accuracy) |
| **3 (3D Fix)** | 3D position with altitude | Best quality fix |

### Dilution of Precision (DOP)

DOP values indicate GPS accuracy (lower is better):

| DOP Value | Rating | Description |
|---|---|---|
| **< 1** | Ideal | Highest possible accuracy |
| **1-2** | Excellent | Very high accuracy |
| **2-5** | Good | Acceptable for most applications |
| **5-10** | Moderate | Consider as approximate |
| **10-20** | Fair | Use with caution |
| **> 20** | Poor | Avoid using position data |

### Cold Start vs Warm Start

| Start Type | Condition | Time to Fix | Description |
|---|---|---|---|
| **Cold Start** | No prior data | 30-60 sec | GPS has no satellite almanac |
| **Warm Start** | Recent data | 5-15 sec | GPS has recent almanac |
| **Hot Start** | Current data | 1-5 sec | GPS recently had fix |

## Troubleshooting

| Issue | Solution |
|---|---|
| **GPS not initializing** | Check wiring (TX→GP5, RX→GP4, VCC→3.3V, GND→GND) |
| | Verify UART1 not in use by other devices |
| | Check GPS module power LED is on |
| **GPS not acquiring fix** | Ensure antenna has clear view of sky |
| | Move away from buildings and trees |
| | Wait 30-60 seconds for cold start |
| | Check satellite count increasing (needs 4+ for fix) |
| **GPS coordinates incorrect** | Verify NMEA sentence parsing (check USB console) |
| | Ensure timezone offset is correct |
| | Wait for HDOP < 5 for better accuracy |
| **GPS coordinates jumping** | Normal with poor satellite geometry |
| | Check HDOP value (should be < 5) |
| | Wait for more satellites in view |
| **No GPS sentences received** | Verify UART baudrate (9600 for NEO-6M) |
| | Check TX/RX pins not swapped |
| | Verify GPS module firmware is working |
| **Time incorrect** | Set GPS_TIMEZONE_OFFSET correctly in code |
| | UTC time from GPS is always correct |
| **9-axis I2C timeout errors** | 10ms delay in main loop prevents this |
| | If persists, increase delay to 20ms |
| **No OLED display** | Check I2C wiring (SCL→GP7, SDA→GP6) and power |
| **OLED garbled text** | Try I2C address 0x3D instead of 0x3C |
| **No UART communication** | Verify TX/RX connections and common ground |
| **Incorrect voltage** | Check voltage divider circuit and calibration |

## Technical Details

### NEO-6M GPS Module Specifications

- **GPS Chipset**: u-blox NEO-6M
- **Channels**: 50 channels
- **Frequency**: L1 (1575.42 MHz)
- **Update Rate**: 1 Hz default (up to 5 Hz)
- **Position Accuracy**: 2.5m CEP (Circular Error Probable)
- **Velocity Accuracy**: 0.1 m/s
- **Time Accuracy**: 30 ns RMS
- **Cold Start Time**: 27 seconds typical
- **Warm Start Time**: 1 second typical
- **Power Consumption**: ~45 mA acquiring, ~30 mA tracking
- **Operating Voltage**: 3.3V
- **Communication**: UART (9600 baud default)

### UART Communication Channels

| UART | Pins | Baudrate | Purpose |
|---|---|---|---|
| UART0 | GP0/GP1 | 9600 bps | XBee communication |
| UART1 | GP4/GP5 | 9600 bps | GPS module communication |

### I2C Communication Channels

| Bus | Pins | Frequency | Address | Purpose |
|-----|---|---|---|---|
| I2C0 | GP6/GP7 | 400 kHz | 0x3C | OLED Display |
| I2C1 | GP20/GP21 | 400 kHz | 0x68, 0x0C | MPU9250 IMU |

### Timing Considerations

The code includes strategic delays to prevent I2C bus contention:

- **10ms delay in main loop**: Prevents GPS UART reading from interfering with I2C
- **50ms delay before 9-axis read**: Ensures I2C bus stability when command 'a' is sent
- **Non-blocking GPS read**: Continuously reads GPS without blocking other operations

## Changes from Step 1

### Hardware Additions
- ✅ NEO-6M GPS sensor module (GY-GPS6MV2)
- ✅ GPS ceramic antenna (usually integrated)
- ✅ UART1 interface (GP4/GP5) for GPS communication

### Software Additions
- ✅ `vyomsat_gps_manager.py` - New module for GPS management
- ✅ NEO-6M handler library for NMEA parsing
- ✅ Command 'g' implementation for GPS diagnostics
- ✅ GPS data integration in regular telemetry
- ✅ Multi-screen OLED GPS display
- ✅ Timezone-aware time conversion

### Functional Improvements
- ✅ Real-time position tracking (latitude, longitude, altitude)
- ✅ GPS time synchronization with local timezone support
- ✅ Speed and course over ground measurement
- ✅ Satellite count and fix quality monitoring
- ✅ Enhanced telemetry with geographic coordinates
- ✅ Comprehensive GPS diagnostics (USB, UART, OLED)
- ✅ Graceful degradation when GPS unavailable or no fix

## Testing Procedure

### 1. Hardware Verification
- [ ] All connections secure and correct
- [ ] GPS antenna positioned with clear view of sky
- [ ] GPS module power LED is on
- [ ] Power supply stable (3.3V to all modules)
- [ ] Common ground connected to all modules

### 2. Software Verification
- [ ] All required libraries uploaded to Pico
- [ ] Main script runs without errors
- [ ] USB console shows successful initialization

### 3. GPS Acquisition Testing
- [ ] GPS initialization message: `[OK] GPS sensor initialized on UART1`
- [ ] Satellite count increases over time (check OLED or command 'g')
- [ ] GPS fix acquired within 60 seconds (outdoor, clear sky)
- [ ] Position coordinates displayed in telemetry

### 4. Command 'g' Testing
- [ ] Wait for GPS fix (Sats > 4)
- [ ] Send 'g' via UART
- [ ] USB console shows comprehensive GPS data
- [ ] UART receives complete position data
- [ ] OLED cycles through 3 screens (6 seconds total)
- [ ] System returns to normal telemetry

### 5. GPS Accuracy Testing
- [ ] Compare GPS coordinates with known location (Google Maps)
- [ ] Check HDOP value (should be < 5 for good accuracy)
- [ ] Verify altitude reading is reasonable
- [ ] Test motion: speed increases when moving
- [ ] Test heading: changes when walking in different directions

### 6. Integration Testing
- [ ] Battery voltage displays correctly
- [ ] OLED shows GPS coordinates when fix available
- [ ] OLED shows "Acquiring..." when no fix
- [ ] UART telemetry includes GPS data every 4 seconds
- [ ] Command 'a' still works (9-axis IMU data)
- [ ] Command 'v' still works (voltage data)
- [ ] All subsystems work together without conflicts

## License

MIT License - Copyright (c) 2025 Ojas Jha

See individual Python files for full license text.

## Author

**Ojas Jha**  
VyomSat CubeSat Education Kit  
Date: October 25, 2025

## Acknowledgments

- Step 0 (EPS + COM) and Step 1 (9-Axis IMU) provide the foundation
- NEO-6M GPS module uses standard NMEA 0183 protocol
- GPS handler library based on community NMEA parsing implementations
- Fritzing diagrams created with Fritzing open-source software

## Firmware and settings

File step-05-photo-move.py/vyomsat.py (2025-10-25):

#!/usr/bin/env python3
# MIT License
#
# Copyright (c) 2025 Ojas Jha
#
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
"""
VyomSat EPS (Electrical Power System) with UART Communication Module
====================================================================

VyomSat - Essence of Space. Built by You.
The CubeSat education kit - Hands-on CubeSat engineering, end-to-end

OVERVIEW:
========
This module combines battery voltage monitoring with UART communication
capabilities for the VyomSat CubeSat education kit. It monitors the
Electrical Power System (EPS) and communicates telemetry data via UART.

FEATURES:
========
- Battery voltage monitoring via ADC
- OLED display for local telemetry visualization
- UART communication for remote telemetry and command reception
- Onboard LED status indication
- Full duplex communication (simultaneous send/receive)

HARDWARE REQUIREMENTS:
=====================
- Raspberry Pi Pico 2 or Pico W microcontroller
- SSD1306 OLED Display (128x64 pixels) connected via I2C:
  * SCL (Serial Clock) → GPIO 7
  * SDA (Serial Data) → GPIO 6
  * VCC → 3.3V
  * GND → Ground
- UART Device (e.g., XBee module) connected to:
  * Pico GP0 (UART0 TX) → Device RX pin
  * Pico GP1 (UART0 RX) ← Device TX pin
  * Pico GP2 → Device RST pin (optional but recommended)
  * Pico GND ↔ Device GND (CRITICAL: Common ground reference)
- Battery voltage divider circuit connected to GP28 (ADC2)
- USB connection for serial output monitoring

WIRING SUMMARY:
==============
- Battery voltage sensing: GP28 (ADC2) via voltage divider
- OLED Display: GP4 (SDA), GP5 (SCL)
- UART Communication: GP0 (TX), GP1 (RX), GP2 (RST - optional)
- Status LED: Built-in LED (GPIO 25 or "LED")
- External GPIO: GP22 for testing (optional)

USAGE:
=====
1. Connect all hardware as described above
2. Upload this script to the Raspberry Pi Pico
3. Run the script
4. System will:
   - Display battery voltage on OLED
   - Send telemetry data via UART
   - Receive and process commands via UART
   - Print status to serial console

SUPPORTED COMMANDS:
==================
Send single character commands via UART:
- 'a': MPU9250 9-axis IMU attitude data (accelerometer, gyroscope, magnetometer)
- 'b': System reset
- 'c': Camera image capture and save to SD card
- 's': SD card data logging (HK + 9-AXIS + GPS)
- 'g': GPS data capture
- 'v': Request voltage reading

AUTHOR: VyomSat CubeSat Education Kit
VERSION: 3.0 - EPS + COM Integration
DATE: 2024
"""

# =============================================================================
# IMPORT STATEMENTS - MICROPYTHON LIBRARIES
# =============================================================================

# MicroPython Hardware Abstraction Layer
import machine
from machine import Pin, SoftI2C

# MicroPython Time Module
import utime

# UART Handler Class
from uart_handler import UartHandler

# OLED Manager
from vyomsat_oled_manager import OledManager

# Battery Manager
from vyomsat_battery_manager import (
    initialize_battery_sensor,
    read_battery_voltage,
    read_and_display_battery_voltage
)

# XBee Manager
from vyomsat_xbee_manager import perform_xbee_hardware_reset

# 9-Axis IMU Manager
from vyomsat_9axis_manager import (
    initialize_9axis_sensor,
    read_and_display_9axis_data,
    is_9axis_available
)

# GPS Manager
from vyomsat_gps_manager import (
    initialize_gps_sensor,
    read_gps_data,
    get_basic_gps_data,
    read_and_display_full_gps_data,
    is_gps_available,
    update_oled_with_gps_and_hk
)

# Camera Manager
from vyomsat_camera_manager import (
    initialize_camera,
    capture_camera_image,
    is_camera_available,
    capture_and_display_image
)

# SD Card Manager
from vyomsat_sd_manager import (
    initialize_sd_card,
    log_sensor_data_to_sd,
    is_sd_card_available,
    log_and_display_sensor_data,
    move_file_to_sd
)

# =============================================================================
# CONFIGURATION CONSTANTS - HARDWARE AND COMMUNICATION SETTINGS
# =============================================================================

# OLED Display Configuration
# ==========================
OLED_SCL_PIN = 7              # Serial Clock Line GPIO pin
OLED_SDA_PIN = 6              # Serial Data Line GPIO pin
OLED_I2C_FREQ = 400000        # I2C bus frequency in Hz (400kHz)
OLED_WIDTH = 128              # Display width in pixels
OLED_HEIGHT = 64              # Display height in pixels
OLED_I2C_ADDR = 0x3C          # Default SSD1306 I2C address

# Battery Monitoring Configuration
# ================================
BATTERY_ADC_CHANNEL = 2              # ADC channel 2 (GPIO 28)
BATTERY_VOLTAGE_REFERENCE = 3.3      # Volts - RP2350 ADC reference
BATTERY_VOLTAGE_DIVIDER_FACTOR = 0.5 # Voltage divider ratio

# UART Configuration
# ==================
UART_INTERFACE_ID = 0         # UART0 interface
UART_TX_PIN = 0               # GP0 - transmit pin
UART_RX_PIN = 1               # GP1 - receive pin
UART_BAUDRATE = 9600          # 9600 bps - standard baudrate
MAX_LINE_BUFFER_SIZE = 256    # 256 bytes - prevents memory overflow

# XBee Reset Pin Configuration (optional but recommended)
# =======================================================
XBEE_RESET_PIN = 2            # GP2 - connected to XBee RST pin
XBEE_INIT_DELAY_SECONDS = 5   # Time to wait after reset

# Timing Configuration
# ====================
MAIN_LOOP_DELAY_SECONDS = 4   # Delay between telemetry transmissions

# SD Card Configuration
# =====================
SD_CS_PIN = 13               # GPIO 13 for Chip Select
SD_SCK_PIN = 10              # GPIO 10 for Serial Clock (SPI1)
SD_MOSI_PIN = 11             # GPIO 11 for Master Out Slave In (SPI1)
SD_MISO_PIN = 12             # GPIO 12 for Master In Slave Out (SPI1)
SD_SPI_ID = 1                # SPI1 interface
SD_BAUDRATE = 1000000        # 1 MHz SPI baudrate

# GPS Sensor Configuration (NEO-6M)
# ==================================
GPS_UART_ID = 1              # UART1 interface
GPS_TX_PIN = 4               # GPIO 4 for UART1 TX
GPS_RX_PIN = 5               # GPIO 5 for UART1 RX
GPS_BAUDRATE = 9600          # NEO-6M default baudrate
GPS_TIMEZONE_OFFSET = 4      # Dubai/UAE timezone (UTC+4)

# 9-Axis IMU Sensor Configuration (MPU9250)
# ==========================================
NINE_AXIS_SCL_PIN = 21       # GPIO 21 for I2C Serial Clock
NINE_AXIS_SDA_PIN = 20       # GPIO 20 for I2C Serial Data
NINE_AXIS_I2C_FREQ = 400000  # I2C bus frequency in Hz (400kHz)

# =============================================================================
# HARDWARE INITIALIZATION
# =============================================================================

# Onboard LED Configuration
# -------------------------
led: Pin = Pin("LED", Pin.OUT)

# External GPIO Pin Configuration (optional)
# -----------------------------------------
power_on_pin: Pin = Pin(22, Pin.OUT)

# Global OLED Manager Object
# --------------------------
oled_manager = None

# Global UART Handler Object
# --------------------------
uart_handler = None

# =============================================================================
# UART COMMAND HANDLING FUNCTIONS
# =============================================================================

def on_command_received_via_uart(character_byte, uart_handler_instance):
    """
    Handle single character commands received via UART.

    This function is called when a single character is received via UART.
    It processes commands and provides appropriate responses via USB, UART,
    and OLED display.

    Supported Commands:
    - 'a': MPU9250 9-axis IMU attitude data capture
    - 'b': System reset
    - 'c': Camera image capture and save to SD card
    - 's': SD card data logging (HK + 9-AXIS + GPS)
    - 'g': GPS data capture
    - 'v': Request voltage reading

    Args:
        character_byte (int): The received byte value (0-255)
        uart_handler_instance (UartHandler): UART handler instance
    """
    # Ensure byte value is in valid range (0-255)
    byte_value = character_byte & 0xFF

    if 32 <= byte_value <= 126:  # Printable ASCII range
        command = chr(byte_value)

        # Display command on OLED immediately
        if oled_manager:
            oled_manager.display_rx_command(command)

        # Print command received via USB (for monitoring)
        print(f"UART Command Received: '{command}' (ASCII: {byte_value})")

        # Process the command
        if command == "a":
            print("Processing MPU9250 9-axis IMU attitude data capture...")
            usb_response = "Command 'a' received: MPU9250 capture initiated"
            uart_response = "ACK: MPU9250 capture initiated"

            # TIMING FIX: Small delay to prevent I2C timeout errors
            # The continuous GPS UART reading in main loop can interfere with
            # I2C bus timing when trying to read 9-axis sensor data.
            # This delay ensures any pending I2C/UART operations complete
            # before attempting to read from MPU9250, preventing [Errno 110]
            # ETIMEDOUT errors on the I2C bus.
            utime.sleep_ms(500)
            
            # Read and display 9-axis attitude data
            # This function will cycle through 4 OLED screens (2 sec each)
            # Total display time: 8 seconds
            read_and_display_9axis_data(uart_handler_instance, oled_manager)
            
            # Brief pause before returning to regular telemetry display
            utime.sleep(1)

        elif command == "b":
            print("Processing system reset...")
            usb_response = "Command 'b' received: System reset initiated"
            uart_response = "ACK: System reset initiated"

        elif command == "c":
            print("Processing camera image capture...")
            usb_response = "Command 'c' received: Camera capture initiated"
            uart_response = "ACK: Camera capture initiated"

            # Capture camera image with OLED display feedback
            # This function handles the entire capture process with
            # status updates displayed on OLED throughout
            captured_image_path = capture_and_display_image(
                uart_handler_instance,
                oled_manager
            )
            
            # If image was captured successfully, move it to SD card
            if captured_image_path is not None:
                # Move image file to SD card with OLED/UART feedback
                # This function handles the entire move process with
                # status updates displayed on OLED and UART responses
                move_file_to_sd(
                    captured_image_path,
                    uart_handler_instance,
                    oled_manager
                )
            
            # Brief pause before returning to regular telemetry display
            utime.sleep(1)

        elif command == "s":
            print("Processing SD card data logging...")
            usb_response = "Command 's' received: SD card logging initiated"
            uart_response = "ACK: SD card logging initiated"

            # Log sensor data to SD card with OLED display feedback
            # This function will cycle through logging 5 data cycles
            # and display status on OLED throughout the process
            log_and_display_sensor_data(uart_handler_instance, oled_manager)
            
            # Brief pause before returning to regular telemetry display
            utime.sleep(1)

        elif command == "g":
            print("Processing GPS data capture...")
            usb_response = "Command 'g' received: GPS capture initiated"
            uart_response = "ACK: GPS capture initiated"

            # Read and display full GPS data
            # This function will cycle through 3 OLED screens (2 sec each)
            # Total display time: 6 seconds
            read_and_display_full_gps_data(uart_handler_instance, oled_manager)
            
            # Brief pause before returning to regular telemetry display
            utime.sleep(1)

        elif command == "v":
            # Voltage request command
            print("Processing voltage request...")
            usb_response = "Command 'v' received: Battery voltage reading initiated"
            uart_response = "ACK: Battery voltage reading initiated"
            
            # Read and display battery voltage with OLED display feedback
            # This function will display voltage on OLED for 2 seconds
            read_and_display_battery_voltage(uart_handler_instance, oled_manager)
            
            # Brief pause before returning to regular telemetry display
            utime.sleep(1)

        else:
            print(f"Unknown command '{command}' received")
            usb_response = f"Unknown command '{command}' - no action taken"
            uart_response = f"NAK: Unknown command '{command}'"

        # Send response via USB (for monitoring)
        print(f"USB Response: {usb_response}")

        # Send response via UART back to the sender
        try:
            uart_response_formatted = f"{uart_response}\r\n"
            bytes_sent = uart_handler_instance.write(
                uart_response_formatted.encode()
            )
            print(f"UART Response sent: '{uart_response}' "
                  f"({bytes_sent} bytes)")
        except Exception as e:
            print(f"Failed to send UART response: {e}")

    else:
        # Display as hexadecimal value
        print(f"UART Command Handler: Control character (0x{byte_value:02X})")
        print("USB Response: Control character received - no action taken")

        # Display control character on OLED
        if oled_manager:
            oled_manager.display_rx_command(f"0x{byte_value:02X}")

        # Send response for control character via UART
        try:
            uart_response = "NAK: Control character"
            uart_response_formatted = f"{uart_response}\r\n"
            bytes_sent = uart_handler_instance.write(
                uart_response_formatted.encode()
            )
            print(f"UART Response sent: '{uart_response}' "
                  f"({bytes_sent} bytes)")
        except Exception as e:
            print(f"Failed to send UART response: {e}")

def on_message_received_via_uart(message_string, uart_handler_instance):
    """
    Handle complete line messages received via UART.

    This function is called when a complete line (terminated by CR/LF)
    is received via UART. It provides custom message handling and sends
    an acknowledgment back via UART and displays on OLED.

    Args:
        message_string (str): The received message string
        uart_handler_instance (UartHandler): UART handler instance
    """
    # Display message on OLED immediately
    if oled_manager:
        oled_manager.display_rx_message(message_string)

    # Custom message processing with enhanced formatting (USB output)
    print(f"Custom UART Message Handler: '{message_string}' "
          f"(Length: {len(message_string)} chars)")

    # Send acknowledgment back via UART
    try:
        ack_message = (f"ACK: Line processed - {len(message_string)} "
                      f"chars received\r\n")
        bytes_sent = uart_handler_instance.write(ack_message.encode())
        print(f"UART Acknowledgment sent: 'Line processed - "
              f"{len(message_string)} chars received' ({bytes_sent} bytes)")
    except Exception as e:
        print(f"Failed to send UART acknowledgment: {e}")

# =============================================================================
# MAIN APPLICATION FUNCTIONS
# =============================================================================
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

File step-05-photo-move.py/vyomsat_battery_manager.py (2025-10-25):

#!/usr/bin/env python3
# MIT License
#
# Copyright (c) 2025 Ojas Jha
#
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
"""
VyomSat Battery Voltage Monitoring Manager
==========================================

This module provides battery voltage monitoring functionality for the VyomSat
CubeSat education kit. It handles ADC initialization and voltage reading
with voltage divider correction.

FEATURES:
========
- Battery voltage monitoring via ADC
- Voltage divider circuit support
- 16-bit ADC resolution
- Error handling and graceful degradation

HARDWARE REQUIREMENTS:
=====================
- Raspberry Pi Pico 2 or Pico W microcontroller
- Battery voltage divider circuit connected to GP28 (ADC2):
  * Battery positive → R1 → GP28 (ADC2) → R2 → GND
  * Example: R1 = 10kΩ, R2 = 10kΩ (voltage divider factor = 0.5)
  * Maximum safe input: 6.6V (with 0.5 divider)

VOLTAGE DIVIDER CONCEPT:
========================
A voltage divider reduces the input voltage to a safe range for the ADC:
- RP2350 ADC can measure 0-3.3V
- Voltage divider allows measurement of higher voltages
- Formula: Vout = Vin * R2 / (R1 + R2)
- Correction: Vin = Vout / voltage_divider_factor

USAGE:
=====
    from vyomsat_battery_manager import (
        initialize_battery_sensor,
        read_battery_voltage
    )

    # Initialize the battery voltage sensor
    initialize_battery_sensor(
        adc_channel=2,
        voltage_reference=3.3,
        voltage_divider_factor=0.5
    )

    # Read battery voltage
    voltage = read_battery_voltage()
    print(f"Battery Voltage: {voltage:.2f}V")

AUTHOR: VyomSat CubeSat Education Kit
VERSION: 1.0
DATE: 2024
"""

# =============================================================================
# IMPORT STATEMENTS - MICROPYTHON LIBRARIES
# =============================================================================

# MicroPython Hardware Abstraction Layer
from machine import ADC

# =============================================================================
# MODULE-LEVEL CONFIGURATION AND STATE
# =============================================================================

# ADC Sensor Object (initialized by initialize_battery_sensor)
_battery_voltage_sensor = None

# ADC Configuration Constants
_voltage_reference = 3.3      # Volts - ADC reference voltage
_adc_max_value = 65535        # Maximum 16-bit ADC reading (2^16 - 1)
_adc_conversion_factor = 0.0  # Calculated during initialization

# Voltage Divider Configuration
_voltage_divider_factor = 0.5  # Factor by which voltage is divided

# =============================================================================
# INITIALIZATION FUNCTIONS
# =============================================================================

def initialize_battery_sensor(adc_channel=2, voltage_reference=3.3,
                              voltage_divider_factor=0.5):
    """
    Initialize the battery voltage sensor on specified ADC channel.

    This function sets up the ADC for battery voltage monitoring and
    calculates the conversion factors needed for accurate voltage readings.

    ADC CONFIGURATION:
    =================
    The RP2350 has a 12-bit ADC, but MicroPython reads it as 16-bit
    (0-65535). The reference voltage is the maximum voltage the ADC
    can measure (typically 3.3V for RP2350).

    VOLTAGE DIVIDER:
    ===============
    If using a voltage divider to measure higher voltages:
    - voltage_divider_factor = R2 / (R1 + R2)
    - Example: R1=10kΩ, R2=10kΩ → factor = 0.5
    - This allows measuring up to 6.6V safely (3.3V / 0.5)

    Args:
        adc_channel (int): ADC channel number (0-2 for GP26-GP28).
                          Default: 2 (GPIO 28)
        voltage_reference (float): ADC reference voltage in volts.
                                  Default: 3.3V
        voltage_divider_factor (float): Voltage divider ratio (0.0-1.0).
                                       Default: 0.5 (50% divider)

    Returns:
        bool: True if initialization successful, False otherwise

    Example:
        >>> initialize_battery_sensor(adc_channel=2, voltage_reference=3.3,
        ...                          voltage_divider_factor=0.5)
        True
    """
    global _battery_voltage_sensor
    global _voltage_reference
    global _adc_conversion_factor
    global _voltage_divider_factor

    try:
        print("BatteryManager: Initializing battery voltage sensor...")
        print(f"  ADC Channel: {adc_channel} (GPIO {26 + adc_channel})")
        print(f"  Voltage Reference: {voltage_reference}V")
        print(f"  Voltage Divider Factor: {voltage_divider_factor}")

        # Store configuration
        _voltage_reference = voltage_reference
        _voltage_divider_factor = voltage_divider_factor

        # Calculate ADC conversion factor
        # This converts raw ADC reading (0-65535) to voltage (0-3.3V)
        _adc_conversion_factor = _voltage_reference / _adc_max_value

        # Initialize ADC on specified channel
        _battery_voltage_sensor = ADC(adc_channel)

        # Calculate maximum measurable voltage
        max_voltage = _voltage_reference / _voltage_divider_factor

        print(f"  ADC Conversion Factor: {_adc_conversion_factor:.10f}")
        print(f"  Maximum Measurable Voltage: {max_voltage:.2f}V")
        print("[OK]BatteryManager: Battery sensor initialized successfully!")

        return True

    except Exception as e:
        print(f"[✗]  BatteryManager: Initialization failed: {e}")
        print("  Continuing without battery monitoring...")
        _battery_voltage_sensor = None
        return False

def is_available():
    """
    Check if the battery voltage sensor is available.

    Returns:
        bool: True if sensor is available, False otherwise
    """
    return _battery_voltage_sensor is not None

# =============================================================================
# VOLTAGE READING FUNCTIONS
# =============================================================================
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

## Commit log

2025-10-25 Added circuit diagrams and BOM
    [eps-com.fzz]
2025-10-25 Added step 1, 9 axis sensor
    [9axis.fzz]
2025-10-25 Added step 2, GPS sensor
    [gps.fzz]
2025-10-25 Added step 3, camera
    [camera.fzz]
2025-10-25 Added step 4, SD card
    [sd.fzz]
2025-10-25 Added step 5, Moving Photo to SD card
    [photo-move.fzz]
